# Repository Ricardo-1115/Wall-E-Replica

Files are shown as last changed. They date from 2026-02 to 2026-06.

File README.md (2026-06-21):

# WALL-E Robot — ESP32-S3 无线图传控制系统

<p align="center">
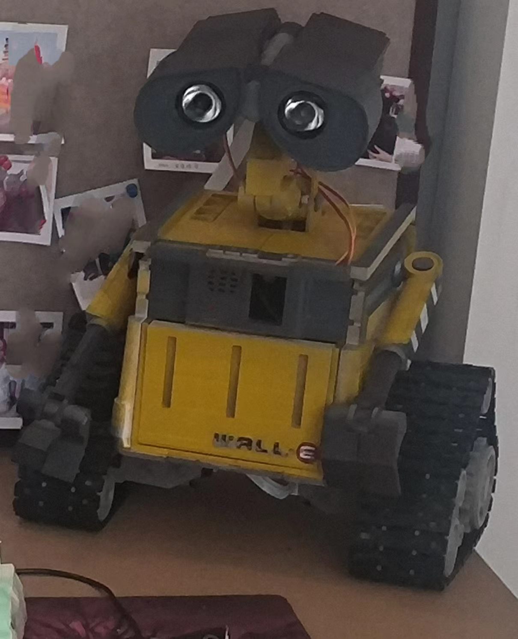
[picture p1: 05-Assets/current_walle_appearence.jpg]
WALL-E 整机外观
  
</p>

<p align="center">
  
  
  
  
</p>

> 深度复刻皮克斯 WALL-E 机器人，从 3D 打印到自研 PCB 再到 ESP-IDF 固件，全栈闭环。
>
> 本科毕业设计项目 —— 基于 ESP32-S3 的移动机器人无线图传系统设计与实现

---

## 目录

- [概述](#概述)
- [实物展示](#实物展示)
- [功能特性](#功能特性)
- [硬件架构](#硬件架构)
- [引脚映射](#引脚映射)
- [快速上手](#快速上手)
- [固件架构](#固件架构)
- [Web 控制面板](#web-控制面板)
- [通信协议](#通信协议)
- [性能测试](#性能测试)
- [硬件设计要点](#硬件设计要点)
- [项目结构](#项目结构)
- [致谢](#致谢)
- [许可证](#许可证)

---

## 概述

本项目全栈自研一台电影级别的 WALL-E 复刻机器人，集无线图传、远程控制、自主行为于一体。

**机械**：基于 [Chillibasket/walle-replica](https://github.com/chillibasket/walle-replica) 开源外壳，经 3D 打印、打磨、组装与喷漆涂装。

**硬件**：自研 12V 三路隔离电源分配板 + ESP32-S3 主控 PCB（窄铜桥接地解决电机地弹干扰）。

**固件**：基于 ESP-IDF 原生框架，FreeRTOS 多任务调度，组件化架构。

**通信**：WiFi STA 模式，WebSocket JSON 全双工协议（单向延迟 < 15ms），MJPEG 实时图传（24 FPS）。

---

## 实物展示

### 3D 打印表面处理

<p align="center">
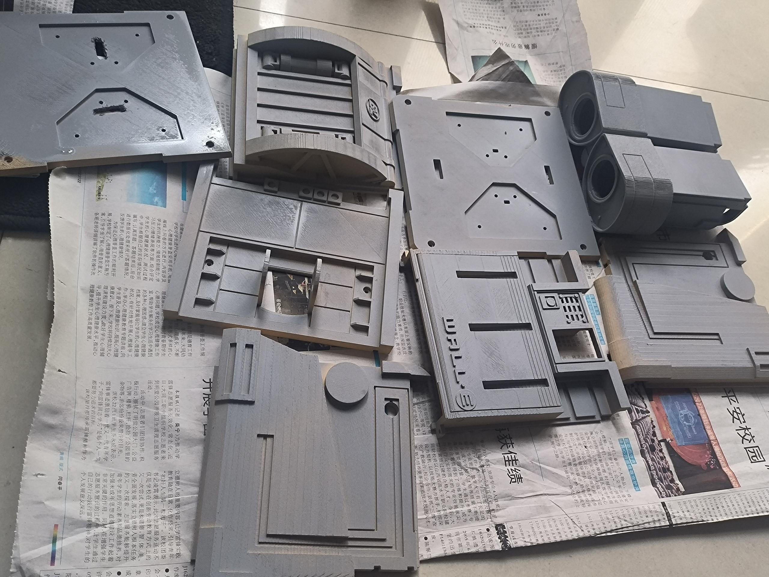
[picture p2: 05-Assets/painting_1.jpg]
喷漆过程
  
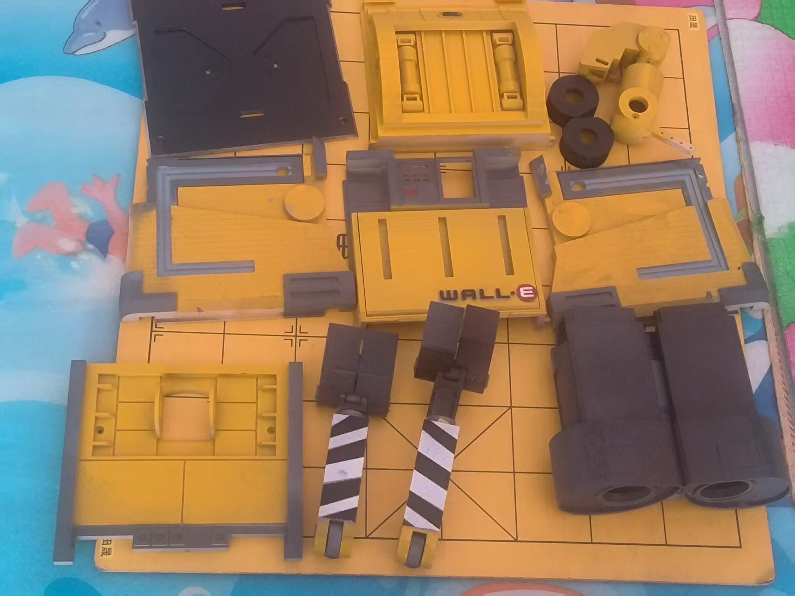
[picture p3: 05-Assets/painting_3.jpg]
喷漆完成
  
</p>

### 主控电路板布局布线

<p align="center">
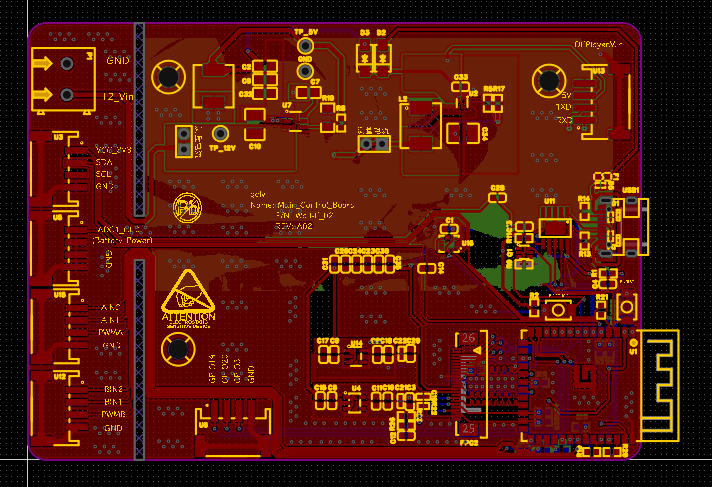
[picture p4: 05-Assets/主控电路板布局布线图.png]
PCB 布局
  
</p>

> 原理图：[02-Hardware/Main_Control_Board/SCH_WALL-E_MB_000_SCH_2026-06-01.pdf](./02-Hardware/Main_Control_Board/SCH_WALL-E_MB_000_SCH_2026-06-01.pdf)

---

## 功能特性

- **无线图传** — OV2640 摄像头 640×480 MJPEG 硬件编码，双缓冲推流，实测 24 FPS
- **全向运动** — 2 路直流电机（TB6612 驱动，LEDC 硬件渐变）+ 7 路舵机关节（PCA9685 驱动，平滑缓动插值）
- **Web 控制面板** — 零安装，手机/PC 浏览器即可操控，支持 Gamepad API 游戏手柄
- **音频交互** — DFPlayer Mini 播放电影原声音效（35+ 音效文件）
- **自主行为** — 8 套预设动画 + 7 种加权随机微表情 + 能量驱动行为决策
- **CLI 调试** — UART 串口控制台提供舵机/电机/音频/NVS 调试命令
- **电池管理** — ADC 电压监测 + 滑动平均滤波 + 低电量加速衰减
- **安全保护** — 电机 800ms 心跳超时自动刹车

---

## 硬件架构

```
                               ┌──────────────────┐
12V LiPo ──► 电源分配板 ──┬──► │ 驱动板 (电机/舵机)│
 (3S)      (3路隔离输出)    │    └──────────────────┘
                           │
                     ┌─────▼──────────────────────────┐
                     │      ESP32-S3 主控板             │
                     │  ┌──────────────────────────┐  │
                     │  │ ESP32-S3-WROOM-1 (N16R8) │  │
                     │  │ 16MB Flash / 8MB PSRAM   │  │
                     │  └──────┬───────┬───────────┘  │
                     │    I2C  │  DVP  │  UART         │
                     │  ┌──────┘       ▼              │
                     │  │    ┌──────────────────┐     │
                     │  │    │ OV2640 摄像头     │     │
                     │  │    │ 640×480 JPEG     │     │
                     │  │    └──────────────────┘     │
                     │  │                             │
                     │  ▼                             │
                     │  ┌──────────────────┐          │
                     │  │ PCA9685 舵机驱动 │──► 7舵机 │
                     │  ├──────────────────┤          │
                     │  │ SSD1306 OLED     │ 128×64   │
                     │  ├──────────────────┤          │
                     │  │ DFPlayer Mini    │──► 喇叭  │
                     │  └──────────────────┘          │
                     └────────────────────────────────┘
```

### 电源分配板
- 12V 输入（3S LiPo），3 路独立输出（PMOS 主开关）
- 保护：TVS + 防反接肖特基 + PTC 自恢复保险 + 两级电容滤波

### 主控板电源树
```
12V ──► TPS54308 (12V→5V, 3A) ──► TLV62569 (5V→3.3V, 2A)
                                      ├── ME6211 (3.3V→2.8V, OV2640 AVDD)
                                      └── ME6211 (3.3V→1.2V, OV2640 DVDD)
```

---

## 引脚映射

| 外设 | 接口 | 引脚 | 备注 |
|---|---|---|---|
| **左电机** | LEDC PWM | GPIO38 | 4kHz, 13-bit |
| | DIR1/2 | GPIO39, GPIO40 | |
| **右电机** | LEDC PWM | GPIO2 | 4kHz, 13-bit |
| | DIR1/2 | GPIO41, GPIO42 | |
| **I2C 总线** | SDA/SCL | GPIO4, GPIO5 | 400kHz, 2.2kΩ 上拉 |
| **PCA9685** | I2C addr | 0x40 | 7 路舵机 |
| **SSD1306 OLED** | I2C addr | 0x3C | 128×64 |
| **DFPlayer Mini** | UART2 TX/RX | GPIO6, GPIO7 | 9600 baud |
| **OV2640 摄像头** | DVP 8-bit | GPIO8~18 | 12 引脚并行 |
| | SCCB (I²C-like) | GPIO47, GPIO48 | 配置总线 |
| **电池 ADC** | ADC1_CH0 | GPIO1 | 2.5dB 衰减, 12-bit |
| **UART0 控制台** | TX/RX | GPIO43, GPIO44 | 通过 CH340K |

---

## 快速上手

### 前置依赖

- [ESP-IDF v5.5](https://docs.espressif.com/projects/esp-idf/en/v5.5/esp32s3/get-started/) 或更高版本
- USB 转 UART 驱动（CH340K）
- Python 3（ESP-IDF 安装时自带）

### 构建

```bash
cd 03-Software/Walle26
idf.py set-target esp32s3
idf.py build
```

### 烧录

```bash
idf.py -p /dev/ttyUSB0 flash   # Linux/macOS
idf.py -p COM3 flash            # Windows
```

### 配置 WiFi

编辑 `sdkconfig.defaults` 中的 WiFi SSID 和密码，或通过 menuconfig 配置：

```bash
idf.py menuconfig
# 路径: WiFi Configuration > WiFi SSID / WiFi Password
```

### 连接

1. 给机器人上电（12V 3S LiPo）
2. 等待 ESP32 连接 WiFi（串口日志查看 IP 地址，`ESP_LOGI("WIFI", "获取到 IP: ...")`）
3. 浏览器访问 `http://<ESP32-IP>` 打开控制面板
4. 视频流地址：`http://<ESP32-IP>:8081/stream`
5. 串口监视器：`idf.py -p <PORT> monitor`

---

## 固件架构

### 组件化分层

```
main.c (初始化 + 任务创建)
│
├── Servo/              PCA9685 I2C 驱动 + 20ms 缓动插值任务
├── DC_Motor/            LEDC 硬件异步渐变 + 800ms 心跳安全刹车
├── wifi/                WiFi STA + HTTP + WebSocket + MJPEG 推流
│   ├── camera_app.c     OV2640 初始化与双缓冲帧管理
│   ├── ws_handler        JSON 指令解析与分发
│   └── index.html        Web 控制面板（内嵌固件）
├── animation_engine/     8 套关键帧动画 + 7 种微表情生成器
├── energy_manager/       0~100 能量值驱动行为决策状态机
├── battery/              ADC 采样 + 8 阶滑窗滤波 + LiPo 查表
├── DFPlayerMini/         UART 串口音频播放
├── command/              CLI 调试命令（舵机/电机/音频/NVS/动画）
└── display/              SSD1306 电池电量显示
```

### 任务调度 (FreeRTOS)

| 核心 | 任务 | 优先级 | 周期 |
|---|---|---|---|
| Core 0 | `wifi_app_task` | — | 事件驱动 |
| Core 1 | `motor_ctrl_task` | 15 | 队列驱动 + 心跳 |
| Core 1 | `servo_fade_task` | — | 20ms |
| Core 1 | `servo_logic_task` | — | 队列驱动 |
| Core 1 | `anim_engine_task` | 8 | 队列驱动 |
| Core 1 | `energy_mgr_task` | 6 | 1s |
| Core 1 | `battery_task` | — | 1s |

### 控制流示例：WebSocket → 舵机

```
浏览器 ── WebSocket JSON ──► ws_handler
                                  │
                            energy_manager ← ENGAGED
                                  │
                            servo_cmd_queue (覆盖写)
                                  │
                            servo_control_task
                                  │
                            walle_joint_move()
                                  │
                            servo_fade_task (20ms 缓动插值)
                                  │
                            PCA9685_set_angle() ──► 舵机
```

### 能量管理行为决策

无人操控时，能量以 0.08/s 衰减（低电量翻倍），自动选择区间对应的动画：

```
 能量 80~100 ── 微表情（7 种加权随机）
 能量 40~80  ── 好奇/探索（预设动画）
 能量 10~40  ── 低落/害羞
 能量 0      ── 假寐姿态
```

WebSocket 有活动时立即切回 `ENGAGED`（能量 = 100），恢复远程控制。

---

## Web 控制面板

内置于固件的 HTML5 控制面板，无需安装任何 App，浏览器访问 `http://<ESP32-IP>` 即可使用。

### 功能

| 功能 | 说明 |
|---|---|
| **实时状态** | HTTP `/status` 轮询显示电量、能量、表情状态 |
| **关节可视化** | 7 路关节进度条实时显示，WebSocket 50ms 高频推送 |
| **链路状态** | 连接/断开/重连指示器 |
| **游戏手柄** | Browser Gamepad API，摇杆控履带，扳机控手臂 |
| **MJPEG 图传** | 640×480 实时视频，按钮启停 |
| **调试面板** | 实时显示收发 JSON 数据帧 |

### 控制台布局示意

```
┌──────────────────────────────────────────────┐
│  ⬡ WALL-E                              78% 😊 │
├──────────────────┬───────────────────────────┤
│  系统             │  关节                     │
│  IP: 192.168.x.x │  头部 ████████░░ 68       │
│  链路 ● ONLINE   │  脖顶 ██████░░░░ 52       │
│  手柄 ● READY    │  左眼 ██░░░░░░░░ 20       │
│                   │  右眼 ████████░░ 70       │
│  动力             │  左臂 ░░░░░░░░░░  0       │
│  左履带 ████ 45   │  右臂 ░░░░░░░░░░  0       │
│  右履带 ███ -30   │                           │
├──────────────────┴───────────────────────────┤
│  📷 启动图传                                   │
├──────────────────────────────────────────────┤
│  {"L":45,"R":-30,"S":[68,52,48,20,70,0,0]}   │
└──────────────────────────────────────────────┘
```

---

## 通信协议

### WebSocket (ws://`<ESP-IP>`/ws)

JSON 格式双向通信：

```json
{
  "L": 50,           // 左履带速度 (-100 ~ 100)
  "R": -30,          // 右履带速度 (-100 ~ 100)
  "S": [50,50,50,50,50,30,30],  // 7 关节角度 (0~100)
  "D": 100           // 舵机动作持续时间 (ms)
}
```

服务端回显收到的帧，用于客户端计算 RTT。

### MJPEG 流 (http://`<ESP-IP>`:8081/stream)

- 协议：`multipart/x-mixed-replace`
- 分辨率：640×480 (VGA)
- 编码：硬件 JPEG
- 帧率：~24 FPS
- 双缓冲：`fb_count = 2`

### REST API

| 端点 | 方法 | 返回 |
|---|---|---|
| `/status` | GET | JSON（电量、能量、WiFi 信号等） |
| `/` | GET | Web 控制面板 HTML |

---

## 性能测试

### WebSocket 延迟（端到端单向）

| 场景 | 单向延迟 |
|---|---|
| 同房间 3m 无遮挡 | **12.46 ms** |
| 隔一堵混凝土墙 5m | **13.22 ms** |
| 隔两堵墙 10m | **48.14 ms** |

所有场景 ≤ 50ms，满足设计指标。

### MJPEG 帧率

| 采样帧数 | 帧率 |
|---|---|
| 100 帧 | 23.6 FPS |
| 500 帧 | **24.2 FPS** |

超设计目标 15 FPS 约 57%。

### 电源纹波

| 转换器 | 开关频率 | 纹波 |
|---|---|---|
| TPS54308 (12V→5V) | 358 kHz | 6.38 mVp-p |
| TLV62569 (5V→3.3V) | 1.27 MHz | 9.70 mVp-p |

<p align="center">
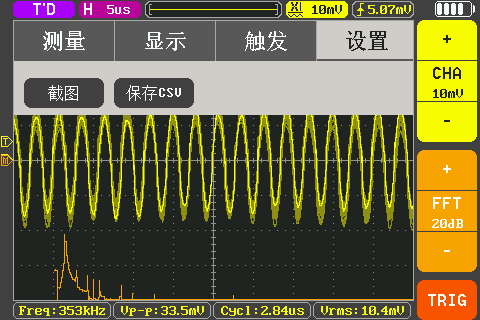
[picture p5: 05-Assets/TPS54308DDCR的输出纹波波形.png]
TPS54308 纹波
  
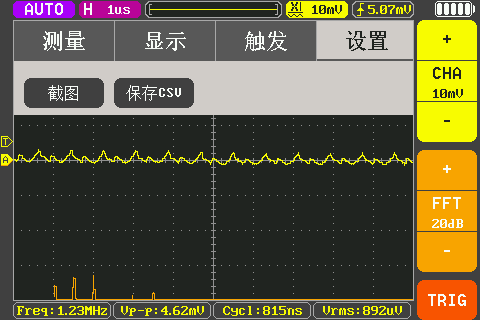
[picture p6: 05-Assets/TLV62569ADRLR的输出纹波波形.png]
TLV62569 纹波
  
</p>

### 舵机精度

控制误差 ±0.5°~1°（受舵机死区限制），优于设计指标 ±2°。

---

## 硬件设计要点

> 本项目的核心难点：电机/舵机感性负载的高频地弹噪声对主控芯片的传导干扰。

### 窄铜桥接地（Split-Ground-Plane Bridge）

PCB 分为洁净区（MCU 数字地）和污染区（电机电源地），中间以 **4~5mm 宽顶底双层覆铜桥** 作为两地唯一连接点：

- **信号回流**：所有跨区信号线紧贴铜桥上方走线，回流紧贴桥底返回，环路面积 ≈ 0
- **噪声扼制**：高频噪声冲击窄桥时，窄覆铜的寄生电感形成扼流效应，将噪声逼回电源粗线路径

辅助措施：PWM 线串联 100Ω 抑制过冲，I²C 2.2kΩ 上拉增强抗扰，XCLK/PCLK 串联 22Ω 保证图像完整性。

---

## 项目结构

```
WallE_Graduation/
├── 01-Spec/                 设计需求、引脚分配、命名规范
├── 02-Hardware/             原理图 (PDF)
│   ├── Power_Distribution_Board/
│   └── Main_Control_Board/
├── 03-Software/Walle26/     ESP-IDF 固件项目
│   ├── main/main.c          主入口
│   ├── Components/          组件化驱动
│   │   ├── Servo/           舵机 (PCA9685 + 平滑动画)
│   │   ├── DC_Motor/        直流电机 (LEDC 渐变)
│   │   ├── DFPlayerMini/    音频
│   │   ├── wifi/            WiFi + WebSocket + MJPEG + Web UI
│   │   ├── animation_engine/ 动画引擎
│   │   ├── energy_manager/  能量管理
│   │   ├── battery/         电池监测
│   │   ├── command/         CLI 调试命令
│   │   └── display/         OLED 显示
│   └── managed_components/  依赖组件
├── 04-Mechanical/           3D 打印 STL (~70 文件)
├── 05-Assets/               照片、视频、音效参考
└── 06-Thesis/               毕业论文 + 流程图 + 参考文献
```

---

## 致谢

### 机械原型
- [Chillibasket/walle-replica](https://github.com/chillibasket/walle-replica) — WALL-E 外壳开源设计

### 技术参考
- Espressif ESP-IDF 物联网开发框架
- TI SPRAAS1B — *Hardware Design Guidelines for TMS320F28xx*
- [Split Ground Planes — The Most Persuasive Argument Yet](https://hott.shielddigitaldesign.com/techtips/split-gnd-plane.html)

### 开源组件
- [nixy4/u8g2](https://components.espressif.com/components/nixy4/u8g2) — OLED 图形库
- [espressif/esp32-camera](https://github.com/espressif/esp32-camera) — 摄像头驱动
- [espressif/esp_jpeg](https://components.espressif.com/components/espressif/esp_jpeg) — JPEG 编解码

### 第三方改进模型
- WALL-E (Tracks strong linkages) — Thingiverse 4932310
- Pinion gear secured with grub screw — Thingiverse 4932959
- WALL-E modified wheel frame — Thingiverse 4832742
- Walle OLED frame — Thingiverse 4800908
- WALL-E paperclip replacement — Thingiverse 4707426
- Accurate Recording Buttons — Thingiverse 5223648

### 原创贡献

1. **平台迁移**：Arduino → ESP-IDF 原生 FreeRTOS 多任务架构
2. **窄铜桥接地**：自研电源分配板 + 混合信号 PCB 布局，解决电机地弹
3. **低延迟通信**：HTTP 轮询 → WebSocket 全双工 JSON，延迟降至 15ms
4. **全功能集成**：图传 + 运动 + 音频 + CLI + 动画 + 能量管理于单一 ESP32-S3
5. **能量行为系统**：单指标 (0~100) 驱动的自主行为决策
6. **零安装 Web 面板**：基于 WebSocket + Gamepad API 的实时操控界面

---

## 许可证

本项目基于 GPL v3 协议开源。

Copyright (C) 2026 gclv (Ricardo-1115)
Copyright (C) 2023 Chillibasket (Original Mechanical Design)

```
This program is free software: you can redistribute it and/or modify
it under the terms of the GNU General Public License as published by
the Free Software Foundation, either version 3 of the License.
```

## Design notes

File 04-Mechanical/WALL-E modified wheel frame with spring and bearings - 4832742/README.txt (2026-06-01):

WALL-E modified wheel frame with spring and bearings by dmdiego on Thingiverse: https://www.thingiverse.com/thing:4832742

Summary:
This is a remix ofhttps://www.thingiverse.com/thing:4285247 andhttps://www.thingiverse.com/thing:4795733So that both bearings and springs can be fitted to the wheel assembly of Wall-EIf needed, file or sandpaper the "functional part" to make it fit properly.My tracks are already using paper clip linkages.https://www.thingiverse.com/thing:4932310https://www.youtube.com/watch?v=lATBx3MUcMY (moves really smooth and quiet)

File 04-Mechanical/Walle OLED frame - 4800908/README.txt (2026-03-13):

Walle OLED frame by ZDC on Thingiverse: https://www.thingiverse.com/thing:4800908

Summary:
I made a frame for using a OLED to monitor a 12v lipo battery.This fits the existing hole, I used some superglue (CA glue) to glue the frame in place.Note the directions of the frame insertAfter I used just a small amount of hot glue to hold the OLED in place.This is OLED I used.https://www.banggood.com/Geekcreit-0_96-Inch-4Pin-White-IIC-I2C-OLED-Display-Module-12864-LED-Geekcreit-for-Arduino-products-that-work-with-official-Arduino-boards-p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

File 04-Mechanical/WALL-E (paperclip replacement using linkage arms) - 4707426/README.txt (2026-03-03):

WALL-E (paperclip replacement using linkage arms) by ZDC on Thingiverse: https://www.thingiverse.com/thing:4707426

Summary:
Remixed from:https://www.thingiverse.com/thing:3703555&amp;https://www.thingiverse.com/thing:4583962Frustrated with trying to figure out how to get the eyes to work with paperclips or the remixed head center I decided why not make simple linkages to connect the eye servos arms to the eye head center piece. I also included the hole as per rene1960's center head design so you can attached the head to his neck piece remixes so you don't have to glue the head to the neck as the original design.The parts I posted are the only ones needed to make this work.In the process I found out my servos needed to be reverse looking at rene1960 photos of the center head remix they did. The original design reference photos from chillibasket showed them the way which is how I originally had them which after trying to wrap my head around how the eyes are suppose work with the servo seemed not correct which seemed odd for how well documented they had everything, but maybe it was just me.I also redesigned the center head piece to make the linkages work.I used M2 machine screws for the connections for the linkages on the 2nd last hole on the servo arms. I drilled the servo hole slightly larger to make the screws fit.Note: The linkages holes are meant so they move freely around the screw attached to the center head piece and servo arm. Also not the direction I attached the machine screws for the linkages, it was hard to get good photos to show how I did it.This is not no other modifications are required to other parts.I also added to extra holes for custom adjustments if needed.If anyone wants STEP versions just comment or send me a message and I can post them.

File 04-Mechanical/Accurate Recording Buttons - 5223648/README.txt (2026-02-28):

Accurate Recording Buttons by Xyphinon on Thingiverse: https://www.thingiverse.com/thing:5223648

Summary:
The original buttons were just circles but the real Wall-e has different shaped buttons, so I made this.

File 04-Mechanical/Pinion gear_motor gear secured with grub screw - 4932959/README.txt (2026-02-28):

Pinion gear/motor gear secured with grub screw by dmdiego on Thingiverse: https://www.thingiverse.com/thing:4932959

Summary:
Remixed the pinion/motor gear to use M4x4mm grub screw to secure it firmly on the motor shaft.

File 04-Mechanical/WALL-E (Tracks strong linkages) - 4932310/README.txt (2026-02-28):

WALL-E (Tracks strong linkages) by ZDC on Thingiverse: https://www.thingiverse.com/thing:4932310

Summary:
I modified the tracks to be strong and use paperclip to connect them.The paperclip idea was from Eisbaeeer tracks that I originally used but they kept breaking on me were the paperclips went though there is not much plastic around them.https://www.thingiverse.com/thing:4069116I also redesigned the front as a gear to help keep the tracking alignment.These track are easy to print and require No support.Connecting the last track/tread &amp; Removing the paperclips can be difficult if you need to remove the tracks/tread.

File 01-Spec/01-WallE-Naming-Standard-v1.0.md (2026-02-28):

# 《WALL-E 机器人及平台编码管理规范》

## 1.目的

定义 "瓦力(WALL-E)" 机器人项目及其衍生平台(ESP32-S3等)的型号命名和序列号规则，确保研发，建模，程序迭代与实物组装的可追溯性。
## 2.适用范围

适用于本项目相关的3D模型版本，固件代码版本，PCB电路板版本及实物组装件。
## 3.产品型号命名规则

### 3.1 项目代号: WALL-E

### 3.2 字段说明

- 型号数字: 三位数组合(示例: 001)

  | 位数 | 代表含义 | 数字含义(0/1/2) |
  |:----:|:--------:|----------------|
  | 第1位 | 核心功能 | 0:图传+运动; 1：带AI功能 |
  | 第2位 | 硬件版本 | 0代表初代，数字随代次逐次增加； |
  | 第3位 | &#x274c; | &#x23f3; |

## 4.软件与文档版本控制

在毕设中，软件迭代最快，需增加版本控制:

- 格式:ProjectName_v [大版本] . [小版本] . [修正版]
- 示例:WallE_Firmware_v1 . 0 . 2
  
---

> **学习**是一个持续的过程，每一小步都是进步。

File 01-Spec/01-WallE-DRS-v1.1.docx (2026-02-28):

设计需求规格说明书

## 1 项目概述

## 1.1项目背景

本项目旨在复刻经典机器人形象 Wall-E，基于开源项目 Chillibasket 的机械结构进行改进。系统采用 ESP32-S3 作为单一主控单元，实现视觉图传、运动控制与人机交互的高度集成化设计。

## 1.2项目目标

实现Wall-E 外观与基本动作复刻和实时视频图传与远程控制。

## 2 系统总体架构设计

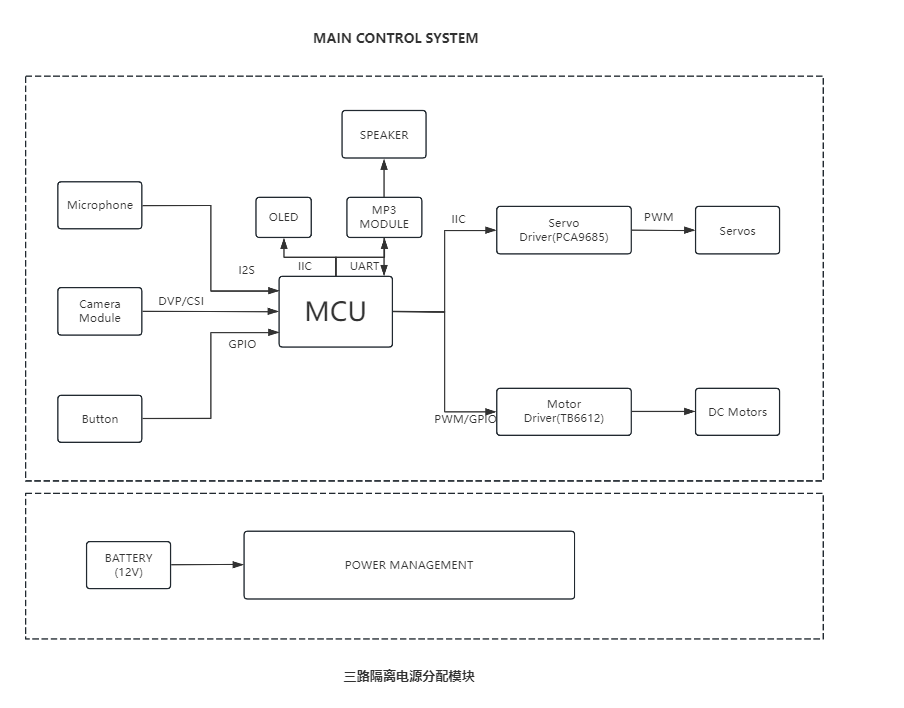
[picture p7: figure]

图2-1 系统硬件架构图

图 2-1 系统硬件架构图系统以 ESP32-S3 为核心控制单元，采用模块化设计。感知层通过 DVP 接口 采集 OV2640 视频流并显示在前端；执行层采用 I2C 总线 通信，通过 PCA9685 扩展芯片实现多路舵机的精准控制，同时利用 TB6612 驱动双路直流电机实现底盘运动。人机交互方面，集成了 1.3寸 OLED 用于状态显示，并通过 UART 串口 控制 MP3 模块实现语音反馈。

由于所用到的电机属于感性负载，在使用过程中容易产生反向电动势，如果将所有电机，主控及传感器的电源供应设计在一起，无疑增加了很大的难度，故Wall-E系统采用一个电源分开供电的策略，自行设计一块 三路隔离电源分配模块(12V-3 Channel Protected Power Distribution )电路板将12V锂电池组的电源分配给伺服电机，直流减速电机，主控板三路（具体如图2-2 电源架构图）

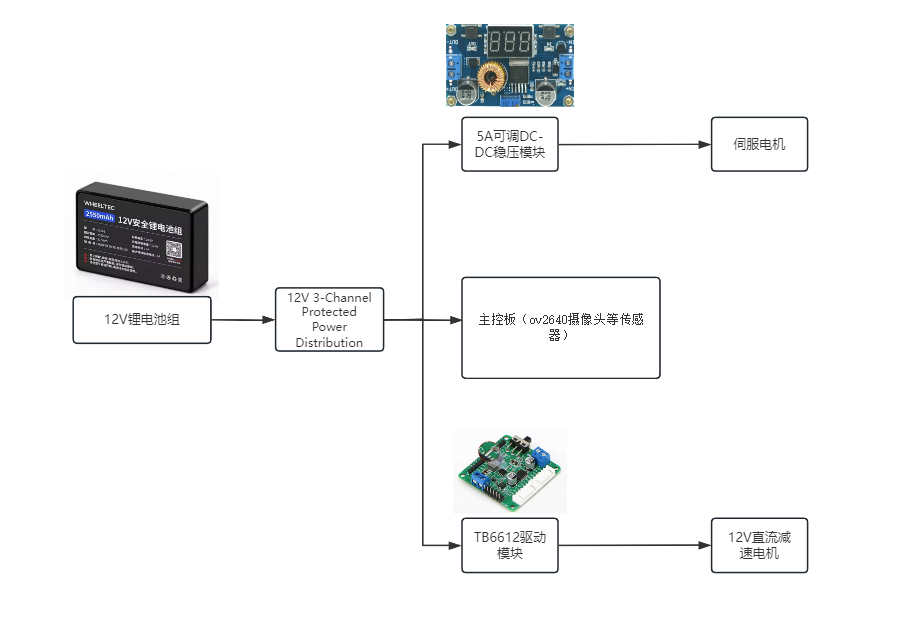
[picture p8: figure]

图2-2 电源架构图

## 3 性能规格

图传：在局域网环境下，实现分辨率不低于 320x240、帧率不低于 15FPS 的视频传输

控制：控制延迟小于 200ms

## 4 硬件接口详细定义

OV2640摄像头：

信号名称 | 分配GPIO | 备注
XCLK | GPIO10 | 外部时钟输入
PCLK | GPIO12 | 像素时钟
VSYNC | GPIO39 | 垂直同步（原JTAG MTCK，需禁用JTAG）
HREF | GPIO40 | 水平参考（原JTAG MTDO，需禁用JTAG）
D0-D7 | GPIO4,5,6,7,15,16,17,18 | 8位并行数据线
SIOD(SDA) | GPIO3 | 摄像头专用I2C数据（Strapping引脚，需外部上拉）
SIOC(SCL) | GPIO41 | 摄像头专用I2C时钟（原JTAG MTDI，需禁用JTAG）

音频系统：

信号名称 | 分配GPIO | 备注
I2S麦克风 SCK | GPIO38 | 麦克风时钟
I2S麦克风 WS | GPIO9 | 麦克风字选择
I2S麦克风 SD | GPIO8 | 麦克风数据
MP3模块 TX | GPIO11 | 串口发送
MP3模块 RX | GPIO21 | 串口接收

显示与舵机：

信号名称 | 分配GPIO | 备注
OLED SDA | GPIO13 | I2C数据（与PCA9685共用总线）
OLED SCL | GPIO14 | I2C时钟（与PCA9685共用总线）

电机驱动：

信号名称 | 分配GPIO | 备注
PWMA | GPIO42 | TB6612 PWM A（原JTAG MTMS，需禁用JTAG）
PWMB | GPIO2 | TB6612 PWM B
AIN1/AIN2 | PCA9685通道 | 通过PCA9685输出，不占用ESP32 GPIO
BIN1/BIN2 | PCA9685通道 | 通过PCA9685输出，不占用ESP32 GPIO

电量检测与调试接口：

信号名称 | 分配GPIO | 备注
Battery Sense | GPIO1 | ADC1_CH0，用于电压采样（ADC2与Wi-Fi冲突，故使用ADC1）
BOOT按钮 | GPIO9 | 按下接地（Strapping引脚，默认上拉，用于下载模式）
USB D- | GPIO8 | 内置USB串口/JTAG的D-，需串联22Ω电阻
USB D+ | GPIO11 | 内置USB串口/JTAG的D+，需串联22Ω电阻
UART0 TXD | GPIO21 | 备用调试输出（默认UART0引脚）
UART0 RXD | | 备用调试输入（默认UART0引脚）

## 5 软件功能与协议定义

视频传输： 采用 HTTP Server Push (MJPEG) 技术，通过独立的 Web Server 线程在 81 端口提供实时视频流，确保在 320x240 分辨率下达到 25FPS 的流畅度。

指令交互： 采用 WebSocket 协议 建立全双工通信通道。

下行指令： 包含电机 PWM 值、舵机角度、MP3 播放控制等，数据格式为 JSON。

上行遥测： 实时回传电池电压（经 ADC 采集）、Wi-Fi 信号强度 (RSSI) 及系统运行时间。

操控扩展性： 前端集成 HTML5 Gamepad API，支持通过标准 Xbox/PS 手柄直接映射控制机器人的运动与云台，实现沉浸式遥控体验。

## 6 机械结构适配说明

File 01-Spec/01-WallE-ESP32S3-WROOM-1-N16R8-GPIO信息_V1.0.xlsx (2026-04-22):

GPIO | 功能 | 注释 | 适用于ESP32-S3-WROOM-1-N16R8
GPIO0 | GPIO0, RTC_GPIO0 | Strapping管脚
GPIO1 | RTC_GPIO1, GPIO1, TOUCH1, ADC1_CH0
GPIO2 | RTC_GPIO2, GPIO2, TOUCH2, ADC1_CH1
GPIO3 | RTC_GPIO3, GPIO3, TOUCH3, ADC1_CH2 | Strapping管脚
GPIO4 | RTC_GPIO4, GPIO4, TOUCH4, ADC1_CH3
GPIO5 | RTC_GPIO5, GPIO5, TOUCH5, ADC1_CH4
GPIO6 | RTC_GPIO6, GPIO6, TOUCH6, ADC1_CH5
GPIO7 | RTC_GPIO7, GPIO7, TOUCH7, ADC1_CH6
GPIO8 | RTC_GPIO8, GPIO8, TOUCH8, ADC1_CH7, SUBSPICS1
GPIO9 | RTC_GPIO9, GPIO9, TOUCH9, ADC1_CH8, FSPIHD, SUBSPIHD
GPIO10 | RTC_GPIO10, GPIO10, TOUCH10, ADC1_CH9, FSPICS0, FSPIIO4, SUBSPICS0
GPIO11 | RTC_GPIO11, GPIO11, TOUCH11, ADC2_CH0, FSPID, FSPIIO5, SUBSPID
GPIO12 | RTC_GPIO12, GPIO12, TOUCH12, ADC2_CH1, FSPICLK, FSPIIO6, SUBSPICLK
GPIO13 | RTC_GPIO13, GPIO13, TOUCH13, ADC2_CH2, FSPIQ, FSPIIO7, SUBSPIQ
GPIO14 | RTC_GPIO14, GPIO14, TOUCH14, ADC2_CH3, FSPIWP, FSPIDQS, SUBSPIWP
GPIO15 | RTC_GPIO15, GPIO15, U0RTS, ADC2_CH4, XTAL_32K_P
GPIO16 | RTC_GPIO16, GPIO16, U0CTS, ADC2_CH5, XTAL_32K_N
GPIO17 | RTC_GPIO17, GPIO17, U1TXD, ADC2_CH6
GPIO18 | RTC_GPIO18, GPIO18, U1RXD, ADC2_CH7, CLK_OUT3
GPIO19 | RTC_GPIO19, GPIO19, U1RTS, ADC2_CH8, CLK_OUT2, USB_D-
GPIO20 | RTC_GPIO20, GPIO20, U1CTS, ADC2_CH9, CLK_OUT1, USB_D+
GPIO21 | RTC_GPIO21, GPIO21
GPIO22 | 不存在
GPIO23
GPIO24
GPIO25
GPIO26 | 该型号模组内部已用于Flash和PSRAM,不可用于其他功能
GPIO27
GPIO28
GPIO29
GPIO30
GPIO31
GPIO32
GPIO33
GPIO34
GPIO35
GPIO36
GPIO37
GPIO38 | GPIO38, FSPIWP, SUBSPIWP
GPIO39 | MTCK, GPIO39, CLK_OUT3, SUBSPICS1
GPIO40 | MTDO, GPIO40, CLK_OUT2
GPIO41 | MTDI, GPIO41, CLK_OUT1
GPIO42 | MTMS, GPIO42
GPIO43 | U0TXD, GPIO43, CLK_OUT1
GPIO44 | U0RXD, GPIO44, CLK_OUT2
GPIO45 | GPIO45 | Strapping管脚
GPIO46 | GPIO46 | Strapping管脚
GPIO47 | SPICLK_P_DIFF, GPIO47, SUBSPICLK_P_DIFF
GPIO48 | SPICLK_N_DIFF, GPIO48, SUBSPICLK_N_DIFF
加粗字体为默认功能

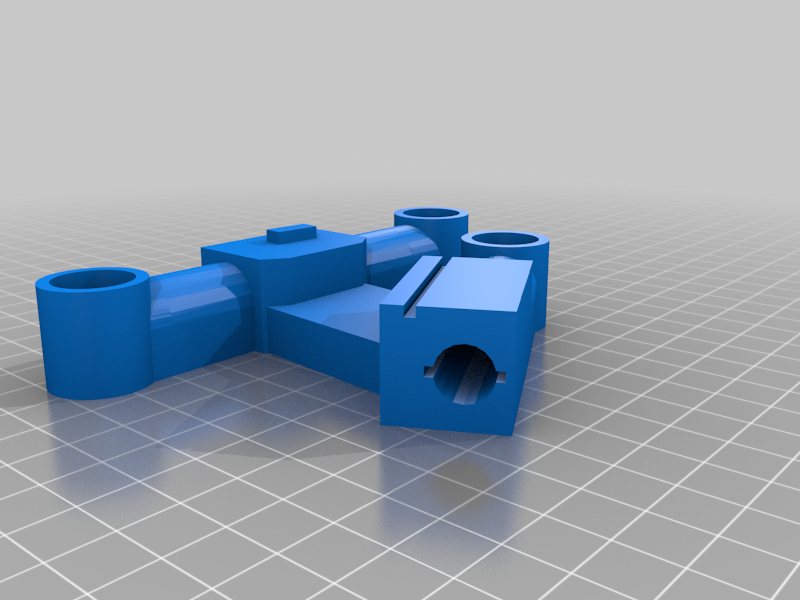
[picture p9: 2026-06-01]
04-Mechanical/WALL-E modified wheel frame with spring and bearings - 4832742/images/Left_Wheel_Frame_Bearings_and_spring.png

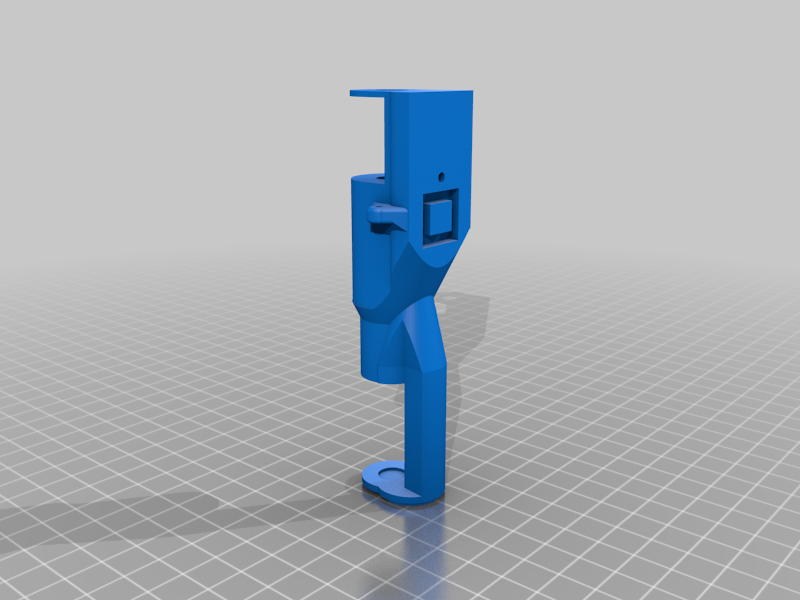
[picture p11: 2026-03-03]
04-Mechanical/WALL-E (paperclip replacement using linkage arms) - 4707426/images/Head_Center_MKIII.png

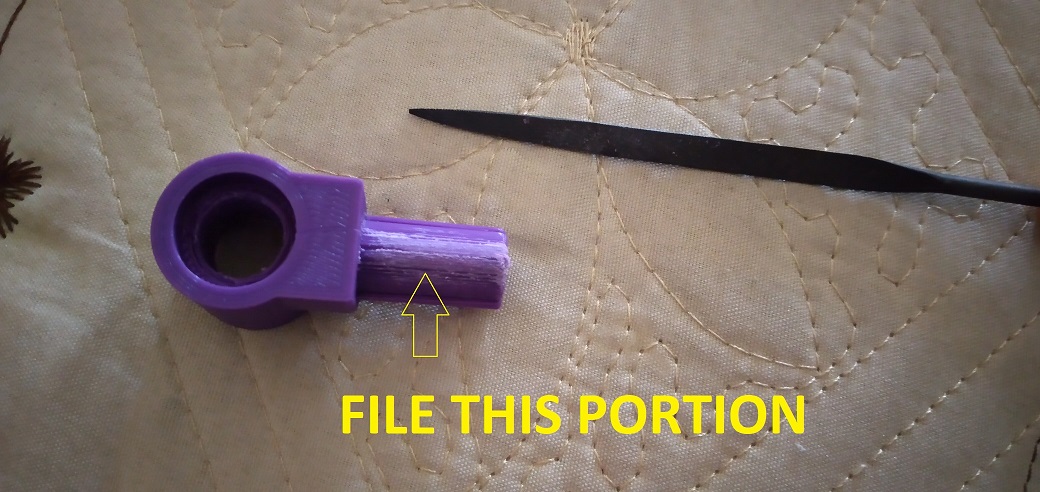
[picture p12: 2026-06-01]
04-Mechanical/WALL-E modified wheel frame with spring and bearings - 4832742/images/20210423_064734_mfnr.jpg

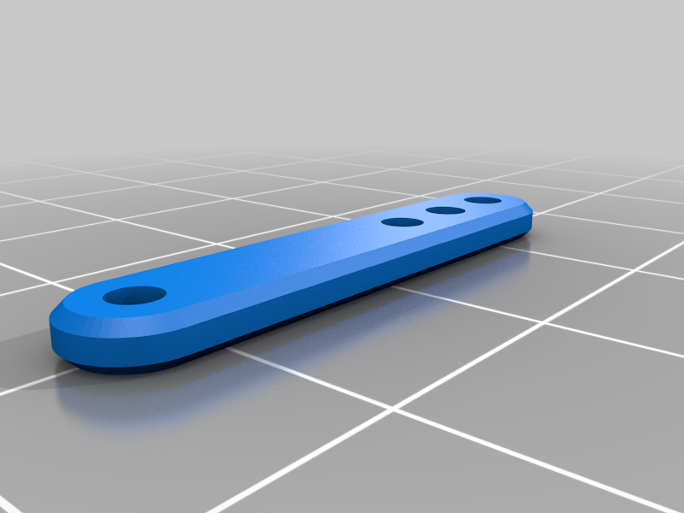
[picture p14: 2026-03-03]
04-Mechanical/WALL-E (paperclip replacement using linkage arms) - 4707426/images/Linkage_MKIII.png

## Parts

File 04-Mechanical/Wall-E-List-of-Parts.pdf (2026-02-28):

3D Printed WALL-E | List of Parts
# | Name | Quantity

3D Printed Components
Body
1 body-bottom | 1
2 body-back | 1
3 body-front | 1
4 body-front-door | 1
5 body-front-pins-x2 | 2
6 body-left | 1
7 body-right | 1
8 body-top | 1
9 body-neck-servo-holder | 1

Arms
10 arm-servo-bracket-left | 1
11 arm-servo-bracket-right | 1
12 arm-hinge-inner-x2 | 2
13 arm-hinge-outer-x2 | 2
14 arm-hinge-axle-x2 | 2
15 arm-barrel-x2 | 2
16 arm-barrel-end-x2 | 2
17 arm-piston-x2 | 2
18 hand-bracket-x2 | 2
19 hand-axle-x2 | 2
20 hand-finger-left-x2 | 2
21 hand-finger-right-x2 | 2
22 hand-finger-middle-x2 | 2

Head
23 head-center | 1
24 head-axle | 1
25 eye-back-left | 1
26 eye-back-right | 1
27 eye-middle-left | 1
28 eye-middle-right | 1
29 eye-front-left | 1
30 eye-front-right | 1
31 eye-camera-replica | 2
32 eye-camera-mount | 0 | <- Use this instead of eye-camera-replica
if you want to add a real camera Neck
33 neck-bottom-axle | 1
34 neck-bottom-left | 1
35 neck-bottom-linkage | 1
36 neck-bottom-right | 1
37 neck-middle-axle | 1
38 neck-top | 1
39 neck-round-bottom | 1

40 neck-round-top-left | 1
41 neck-round-top-right | 1
42 neck-wire-guide-left | 1
43 neck-wire-guide-right | 1
44 neck-top-linkage | 1

Wheels
45 wheel-back-x4 | 4
46 wheel-front-x4 | 4
47 wheel-top-x8 | 8
48 wheel-gear-driven-x2 | 2
49 wheel-gear-motor-x2 | 2
50 wheel-axle-notched-x6 | 6
51 wheel-axle-back-x2 | 2
52 wheel-axle-spacer-x8 | 8
53 wheel-frame-left | 1
54 wheel-frame-right | 1
55 wheel-frame-addon-x2 | 2
56 wheel-bracket-inner-left | 1
57 wheel-bracket-inner-right | 1
58 wheel-bracket-outer-left | 1
59 wheel-bracket-outer-right | 1

Tanks Treads
60 tread-plate-x70 | 70
61 tread-pin-x140 | 140
Total | 310

Hardware
h1 linkage bar (paper clip) | 2
h2 M3 Bolt - 10mm length | 14
h3 M3 Bolt - 20mm length | 12
h4 M3 Nut | 26

Electronics
e1 Micro Servo Motor | 7
e2 12v Geared DC Motor | 2
e3 Arduino Uno (or equivalent) | 1
e4 Motor Controller Shield | 1
e5 i2c Servo Controller | 1
e6 12v Battery Pack | 1
e7 12V to 5V Buck Converter | 1
e8 Raspberry Pi | 1 | Optional
e9 5v Battery Pack | 1
e10 USB Camera | 1
e11 Small Speaker | 1

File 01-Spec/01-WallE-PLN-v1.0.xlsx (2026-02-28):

阶段 | 编号 | 任务名称 | 核心产出物 | 开始日期 | 预计结束日期 | 状态 | 关键点
Z1:筹备 | 1.1 | 需求功能梳理 | 设计规格书（DRS） | 2026-01-16 | 2026-02-04 | 完成
Z2:结构 | 2.1 | Fusion软件学习，熟悉3D建模设计 | Wall-E初步3D结构 | 2026-01-20 | 2026-02-14 | 进行中
 | 2.2 | 3D打印机相关学习使用 | Wall-E最终3D结构 | 2026-02-15 | 2026-03-15 | 待开始
Z3:硬件 | 3.1 | 硬件电路设计 | PCBA,BOM | 2026-02-20 | 2026-04-01 | 待开始
Z4:软件 | 4.1 | 熟悉开发环境（ESP-IDF）及相关组件驱动 | 软件设计文档 | 2026-01-20 | 2026-02-14 | 待开始 | 验证摄像头驱动
 | 4.2 | 软件通讯协议 |  | 2026-01-20 |  | 待开始
 | 4.3 | 软件源代码 |  | 2026-03-03 |  | 待开始
Z5:交付 | 5.1 | 最终联调，文档整理撰写，产品宣发 | 毕业设计论文 |  |  | 待开始

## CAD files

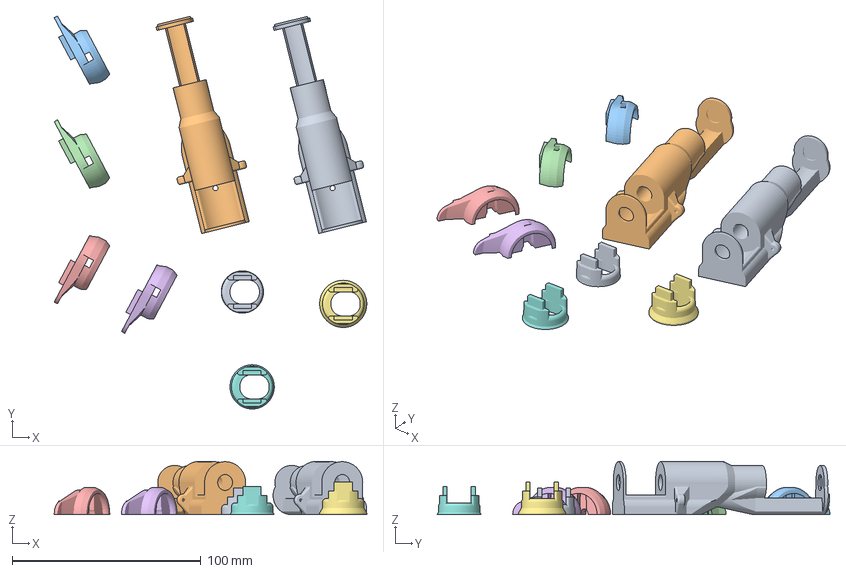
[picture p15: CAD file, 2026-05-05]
04-Mechanical/001_Original_Files/arm-barrel-end-x2.3mf
165.4 x 208.0 x 28.2 mm
Head_Center_MKIII.stl x 2
neck-round-top-left.STL x 2
neck-round-top-right.STL x 2
neck-round-bottom.STL
neck-round-bottom.STL_B x 2

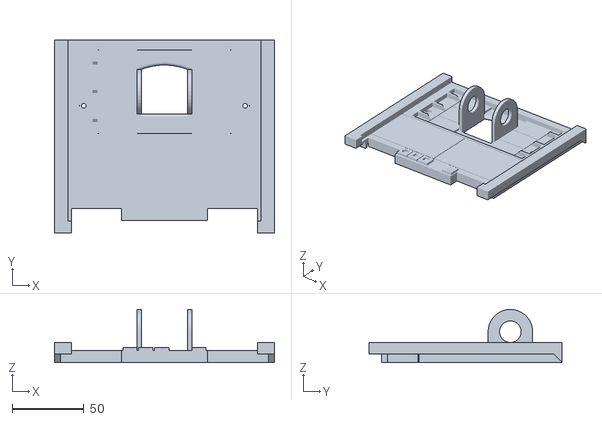
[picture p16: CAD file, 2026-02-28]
04-Mechanical/Accurate Recording Buttons - 5223648/files/New_Wall-e_Top.stl
153.0 x 134.4 x 37.0

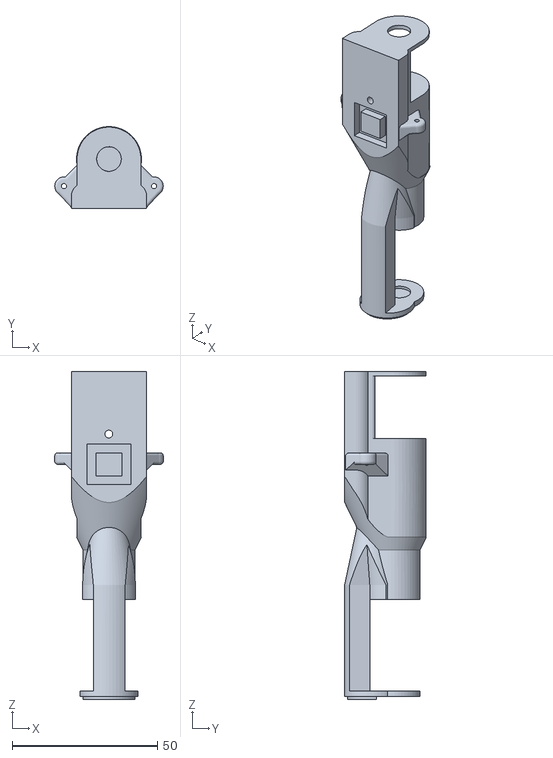
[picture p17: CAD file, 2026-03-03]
04-Mechanical/WALL-E (paperclip replacement using linkage arms) - 4707426/files/Head_Center_MKIII.stl
37.4 x 28.2 x 113.0

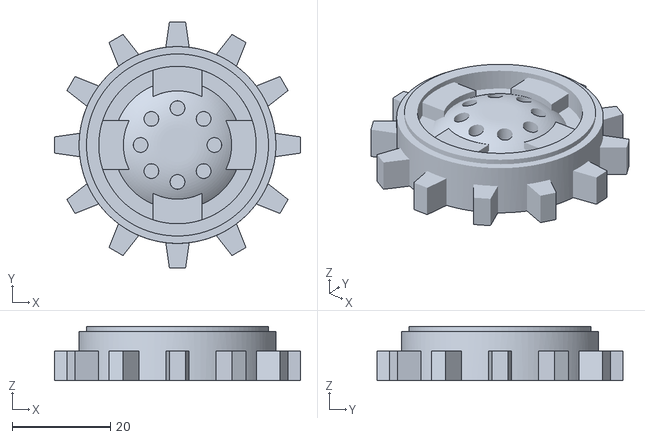
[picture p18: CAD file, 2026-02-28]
04-Mechanical/WALL-E (Tracks strong linkages) - 4932310/files/wheel-frontx4_MKII.stl
50.0 x 50.0 x 11.0

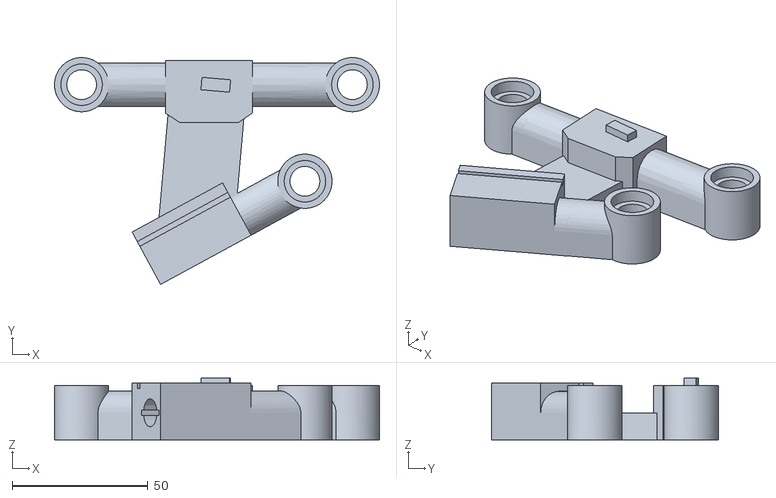
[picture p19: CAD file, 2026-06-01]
04-Mechanical/WALL-E modified wheel frame with spring and bearings - 4832742/files/Left_Wheel_Frame_Bearings_and_spring.stl
119.9 x 83.7 x 22.8

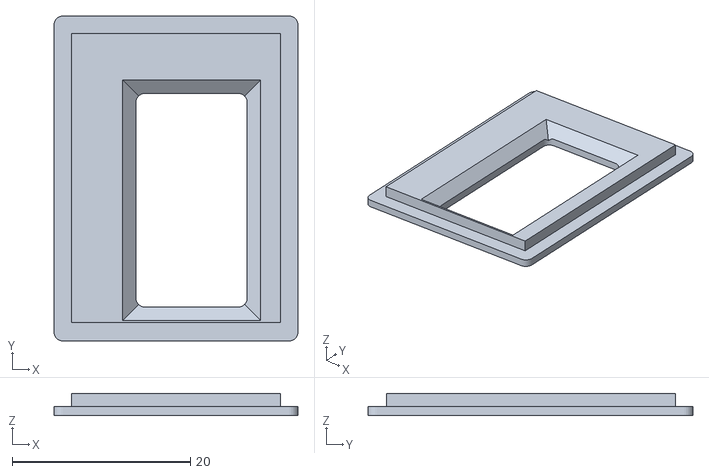
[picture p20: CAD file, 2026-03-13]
04-Mechanical/Walle OLED frame - 4800908/files/OLED_frame_v2.stl
27.4 x 36.5 x 2.50

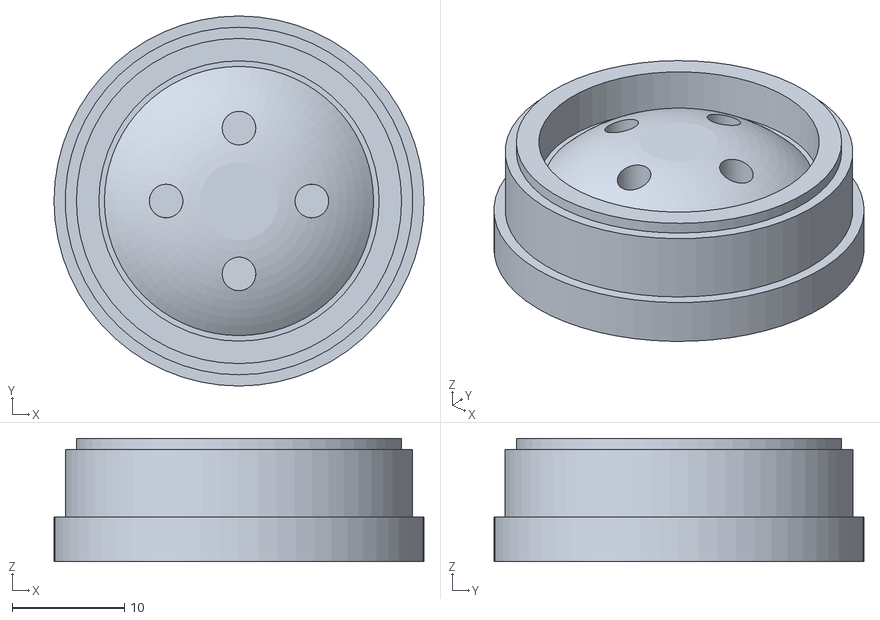
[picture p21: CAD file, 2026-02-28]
04-Mechanical/001_Original_Files/wheel-top-larger-x0.STL
33.0 x 33.0 x 11.0

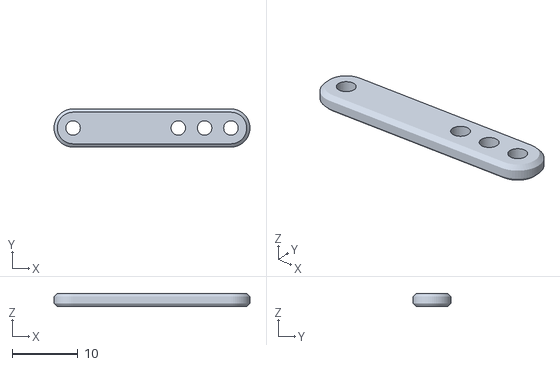
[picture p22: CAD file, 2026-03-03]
04-Mechanical/WALL-E (paperclip replacement using linkage arms) - 4707426/files/Linkage_MKIII.stl
29.8 x 5.80 x 2.00

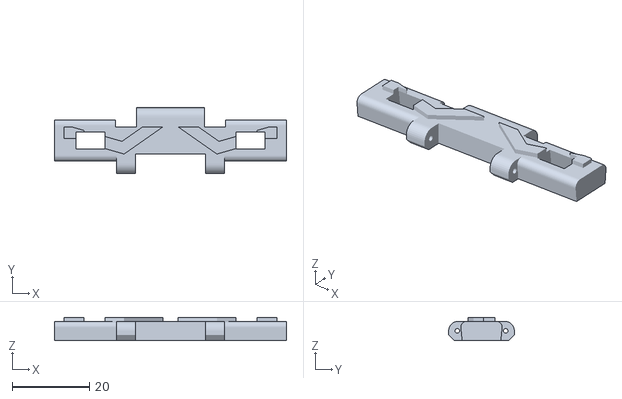
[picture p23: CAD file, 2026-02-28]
04-Mechanical/WALL-E (Tracks strong linkages) - 4932310/files/Tread_MKII.stl
60.0 x 17.0 x 6.00

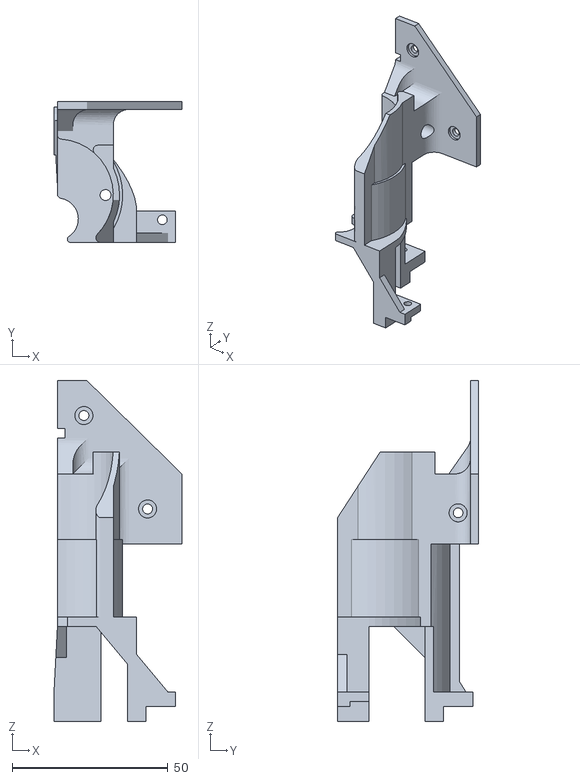
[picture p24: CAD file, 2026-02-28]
04-Mechanical/001_Original_Files/wheel-bracket-outer-left.STL
41.0 x 45.2 x 109.5

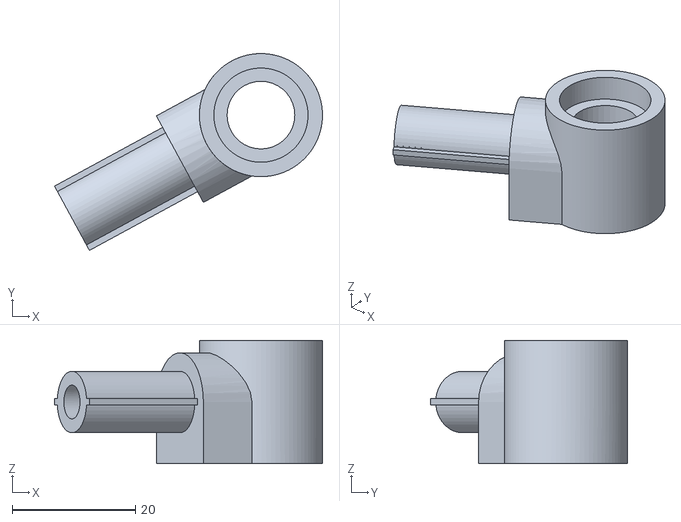
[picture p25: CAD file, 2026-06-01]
04-Mechanical/WALL-E modified wheel frame with spring and bearings - 4832742/files/functional_part_x_2.stl
43.5 x 32.0 x 20.0

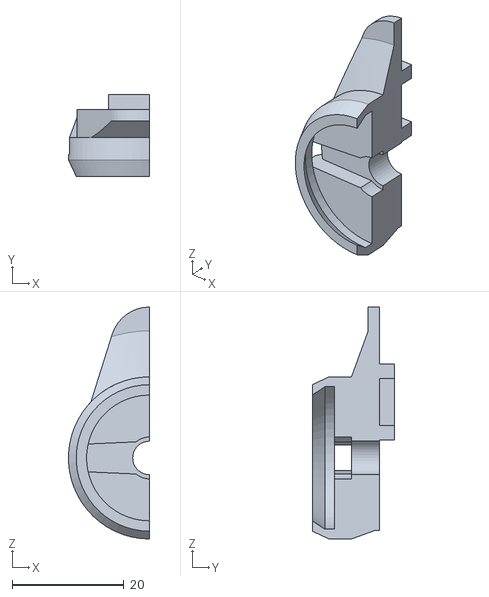
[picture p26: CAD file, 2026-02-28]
04-Mechanical/001_Original_Files/neck-round-top-left.STL
14.5 x 14.7 x 41.5

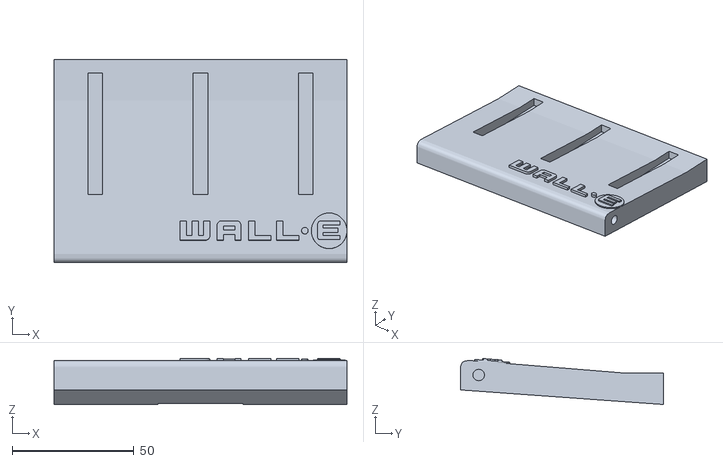
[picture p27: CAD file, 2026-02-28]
04-Mechanical/001_Original_Files/body-front-door.STL
120.5 x 83.5 x 18.9

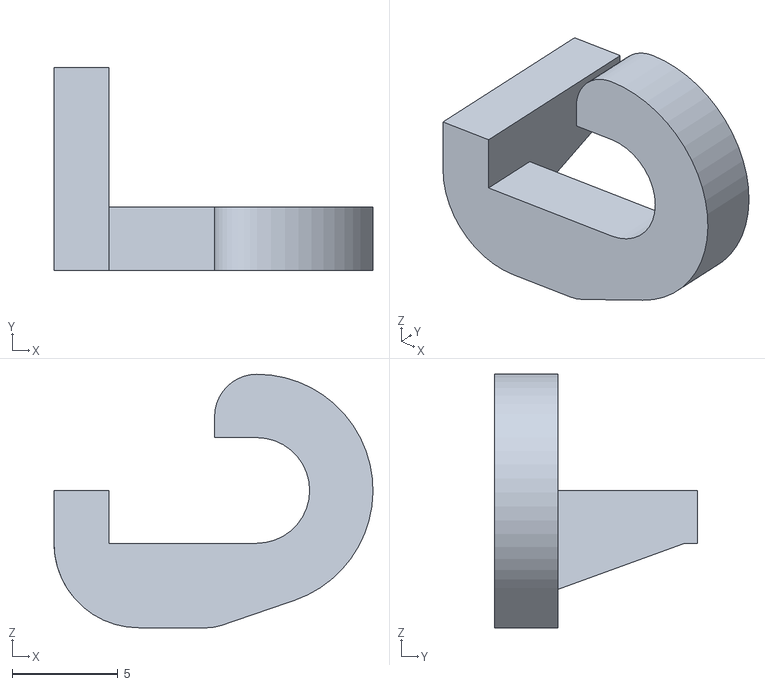
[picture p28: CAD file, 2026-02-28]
04-Mechanical/001_Original_Files/neck-wire-guide-right.STL
15.1 x 9.60 x 12.0

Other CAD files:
04-Mechanical/WALL-E modified wheel frame with spring and bearings - 4832742/files/Right_Wheel_Frame_Bearings_and_spring..stl
04-Mechanical/001_Original_Files/eye-back-left.STL
04-Mechanical/001_Original_Files/body-neck-servo-holder.STL
04-Mechanical/001_Original_Files/wheel-frame-right.STL
04-Mechanical/001_Original_Files/arm-barrel-end-x2.STL
04-Mechanical/001_Original_Files/arm-barrel-x2.3mf
04-Mechanical/001_Original_Files/arm-barrel-x2.STL
04-Mechanical/001_Original_Files/arm-hinge-axle-x2.STL
04-Mechanical/001_Original_Files/arm-hinge-inner-x2.STL
04-Mechanical/001_Original_Files/arm-hinge-outer-x2.STL
04-Mechanical/001_Original_Files/arm-piston-x2.STL
04-Mechanical/001_Original_Files/arm-servo-bracket-left.STL
04-Mechanical/001_Original_Files/arm-servo-bracket-right.STL
04-Mechanical/001_Original_Files/body-back.STL
04-Mechanical/001_Original_Files/body-bottom.STL
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

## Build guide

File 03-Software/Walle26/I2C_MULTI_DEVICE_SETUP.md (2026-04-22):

# I2C 一主多从集成方案

## 概述

本方案实现了 ESP32 中 **I2C 一主多从** 的集中管理，在**同一条 I2C 总线**（I2C_NUM_0）上连接多个从设备：

- **PCA9685**（PWM/舵机控制器）- 地址 `0x40`
- **SSD1306 OLED**（显示屏）- 地址 `0x3C`

### 硬件连接

- **I2C 引脚**：SDA = GPIO38，SCL = GPIO14
- **时钟速率**：400 kHz
- **通信协议**：I2C Master with multiple I2C Slave devices

---

## 系统架构

### 之前的问题

```
❌ PCA9685.c        创建自己的 I2C 总线（重复初始化）
❌ main.c (U8G2)    创建另一条 I2C 总线
→ 结果：两条独立的 I2C 总线，浪费资源，可能冲突
```

### 改进后的架构

```
✅ main.c
   └─ init_i2c_bus()           ← 创建唯一的 I2C 总线
      |
      ├─ init_servo_hardware()  ← 使用共享总线
      |  └─ servo_hw_init(bus_handle)
      |
      └─ init_oled_display()   ← 使用共享总线
         └─ u8g2_esp32_i2c_init_with_bus(ctx, bus_handle)
```

---

## 修改详情

### 1. **PCA9685.c** - 添加支持外部 bus_handle

**新增函数：**

```c
esp_err_t pca9685_init_with_bus(i2c_master_bus_handle_t bus_handle)
```

**原有函数保留（向后兼容）：**

```c
esp_err_t pca9685_init(void)  // 仍然自创 I2C 总线
```

### 2. **Servo.h** - 暴露新的初始化 API

```c
// 原始初始化（自动创建 I2C 总线）
esp_err_t pca9685_init(void);

// 新增：使用外部 I2C 总线初始化（支持一主多从）
esp_err_t pca9685_init_with_bus(i2c_master_bus_handle_t bus_handle);
```

### 3. **esp32_hw_i2c.h/.c** - U8G2 OLED 驱动升级

**新增函数：**

```c
esp_err_t u8g2_esp32_i2c_init_with_bus(
    u8g2_esp32_i2c_ctx_t *ctx, 
    i2c_master_bus_handle_t bus_handle
)
```

**功能：** 不创建新的 I2C 总线，而是使用外部提供的总线句柄

### 4. **main.c** - 集中管理所有 I2C 设备

**四个初始化层次：**

#### `init_i2c_bus()` - 初始化唯一的 I2C 总线

```c
static esp_err_t init_i2c_bus(void)
{
    i2c_master_bus_config_t bus_config = {
        .i2c_port = I2C_NUM_0,
        .sda_io_num = GPIO_NUM_38,
        .scl_io_num = GPIO_NUM_14,
        .clk_source = I2C_CLK_SRC_DEFAULT,
        .glitch_ignore_cnt = 7,
        .flags.enable_internal_pullup = 1,
    };

    return i2c_new_master_bus(&bus_config, &g_i2c_bus_handle);
}
```

#### `init_servo_hardware()` - 初始化舵机硬件

```c
static esp_err_t init_servo_hardware(void)
{
    esp_err_t err = servo_hw_init(g_i2c_bus_handle);
    return err;
}
```

#### `init_oled_display()` - 初始化 OLED 显示屏

```c
static esp_err_t init_oled_display(void)
{
    u8g2_esp32_i2c_ctx_t i2c_ctx = {
        .cfg = U8G2_ESP32_I2C_CONFIG_DEFAULT(),
    };

    esp_err_t err = u8g2_esp32_i2c_init_with_bus(&i2c_ctx, g_i2c_bus_handle);

    u8g2_Setup_ssd1306_i2c_128x64_noname_f(&u8g2, U8G2_R0,
        u8x8_byte_esp32_hw_i2c, u8x8_gpio_and_delay_esp32_i2c);

    u8g2_InitDisplay(&u8g2);
    u8g2_SetPowerSave(&u8g2, 0);
    return err;
}
```

---

## 新的组件边界

### `servo_hw_init()` 和 `servo_app_init()` 的职责

- `servo_hw_init(i2c_master_bus_handle_t bus_handle)`
  - 负责 PCA9685 硬件初始化与频率设置
  - 属于“硬件初始化层”
- `servo_app_init()`
  - 负责舵机命令队列、任务启动与业务逻辑
  - 不再负责硬件初始化

---

## 使用示例

### 基本初始化流程

```c
void app_main(void)
{
    // 1. 初始化唯一的 I2C 总线
    if (init_i2c_bus() != ESP_OK) {
        ESP_LOGE(TAG, "I2C 初始化失败");
        return;
    }

    // 2. 在同一总线上添加 OLED 设备
    if (init_oled_display() != ESP_OK) {
        ESP_LOGW(TAG, "OLED 初始化失败，但继续运行");
    }

    // 3. 在同一总线上添加舵机控制器
    if (init_servo_hardware() != ESP_OK) {
        ESP_LOGW(TAG, "舵机硬件初始化失败，但继续运行");
    }

    // 正常使用
    pca9685_set_angle(0, 90.0f);  // 舵机动作
    u8g2_DrawStr(&u8g2, 0, 10, "Hello");  // 显示文字
}
```

---

## 关键优势

| 方面 | 之前 | 改进后 |
| --- | --- | --- |
| **I2C 总线数量** | 2 条（浪费资源）  | 1 条（共享） |
| **代码重复** | 每个设备都初始化总线 | 只初始化一次 |
| **灵活性** | 低（硬编码总线配置） | 高（参数化） |
| **扩展性** | 差（难以添加新设备） | 好（在同一总线上添加） |
| **资源占用** | 更多 | 更少 |

---

## 添加新 I2C 设备的步骤

假设要添加第三个 I2C 设备（如温度传感器，地址 `0x48`）：

1. **编写驱动程序**（支持外部 bus_handle）：
   
   ```c
   esp_err_t temp_sensor_init_with_bus(i2c_master_bus_handle_t bus_handle)
   {
       // 将 bus_handle 传给驱动初始化函数
   }
   ```

2. **在 main.c 中添加初始化函数**：
   
   ```c
   static esp_err_t init_temp_sensor(void)
   {
       return temp_sensor_init_with_bus(g_i2c_bus_handle);
   }
   ```

3. **在 app_main 中调用**：
   
   ```c
   init_temp_sensor();
   ```

无需修改 I2C 总线配置，直接添加即可！

---

## 故障排除

### 问题：OLED 无法显示

**检查项：**

- OLED 地址是否为 `0x3C`（配置中 `.dev_addr_7bit = 0x3C`）
- SDA/SCL 引脚是否正确（GPIO38/GPIO14）
- I2C 总线是否正确初始化

### 问题：舵机不动作

**检查项：**

- PCA9685 地址是否为 `0x40`（头文件中 `#define PCA_Addr 0x40`）
- PCA9685_init_with_bus 是否成功返回
- `pca9685_set_freq(50)` 是否被调用

### 问题：两个设备同时出错

**检查项：**

- I2C 总线是否初始化成功（检查返回值）
- I2C 引脚是否被正确配置
- ESP32 是否启用了内部上拉电阻

---

## 参考资源

- **ESP32 I2C Master API**：https://docs.espressif.com/projects/esp-idf/en/latest/esp32/api-reference/peripherals/i2c.html
- **u8g2 库**：https://github.com/olikraus/u8g2
- **PCA9685 数据手册**：https://www.nxp.com/docs/en/data-sheet/PCA9685.pdf

---

## 总结

✅ **一条 I2C 总线** - 共享 SDA/SCL 引脚  
✅ **多个从设备** - 使用不同地址（0x40, 0x3C, ...）  
✅ **集中管理** - 在 main.c 中管理所有初始化  
✅ **易于扩展** - 添加新设备只需实现 `xxx_init_with_bus(bus_handle)`  
✅ **向后兼容** - 原有 `pca9685_init()` 仍可单独使用，新的 `servo_hw_init()` 供共享 I2C 总线时使用

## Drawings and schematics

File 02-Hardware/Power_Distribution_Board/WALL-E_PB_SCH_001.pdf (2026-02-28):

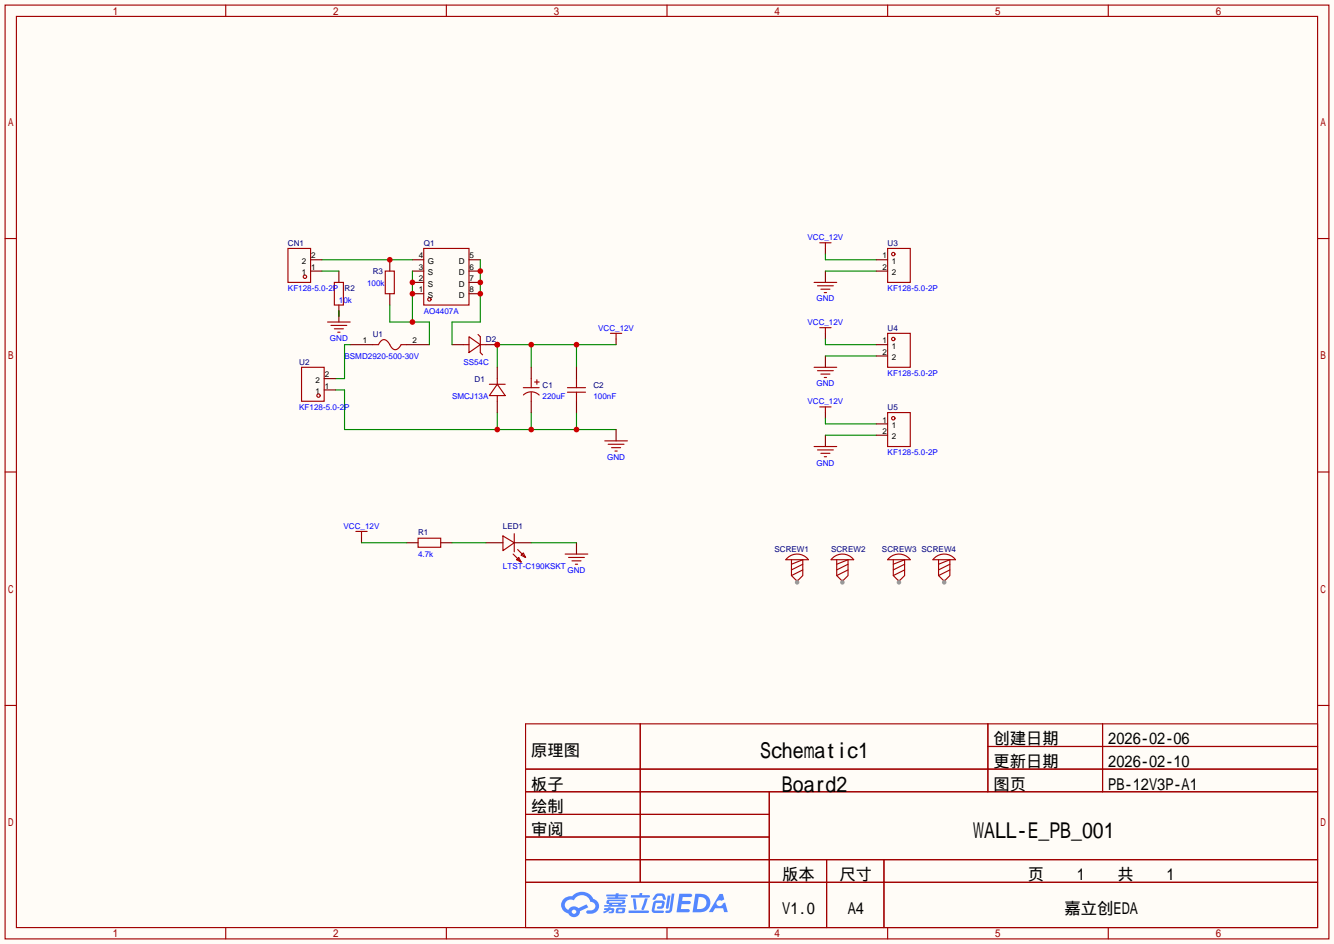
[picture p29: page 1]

原理图 | Schematic1 | 创建日期 | 2026-02-06

更新日期 | 2026-02-10

板子 | Board2 | 图页 | PB-12V3P-A1
绘制 | | WALL-E_PB_001
审阅

V1.0 | A4 | 嘉立创EDA

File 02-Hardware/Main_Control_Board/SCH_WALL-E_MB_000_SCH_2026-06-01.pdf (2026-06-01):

# DC-DC

# 电源电路

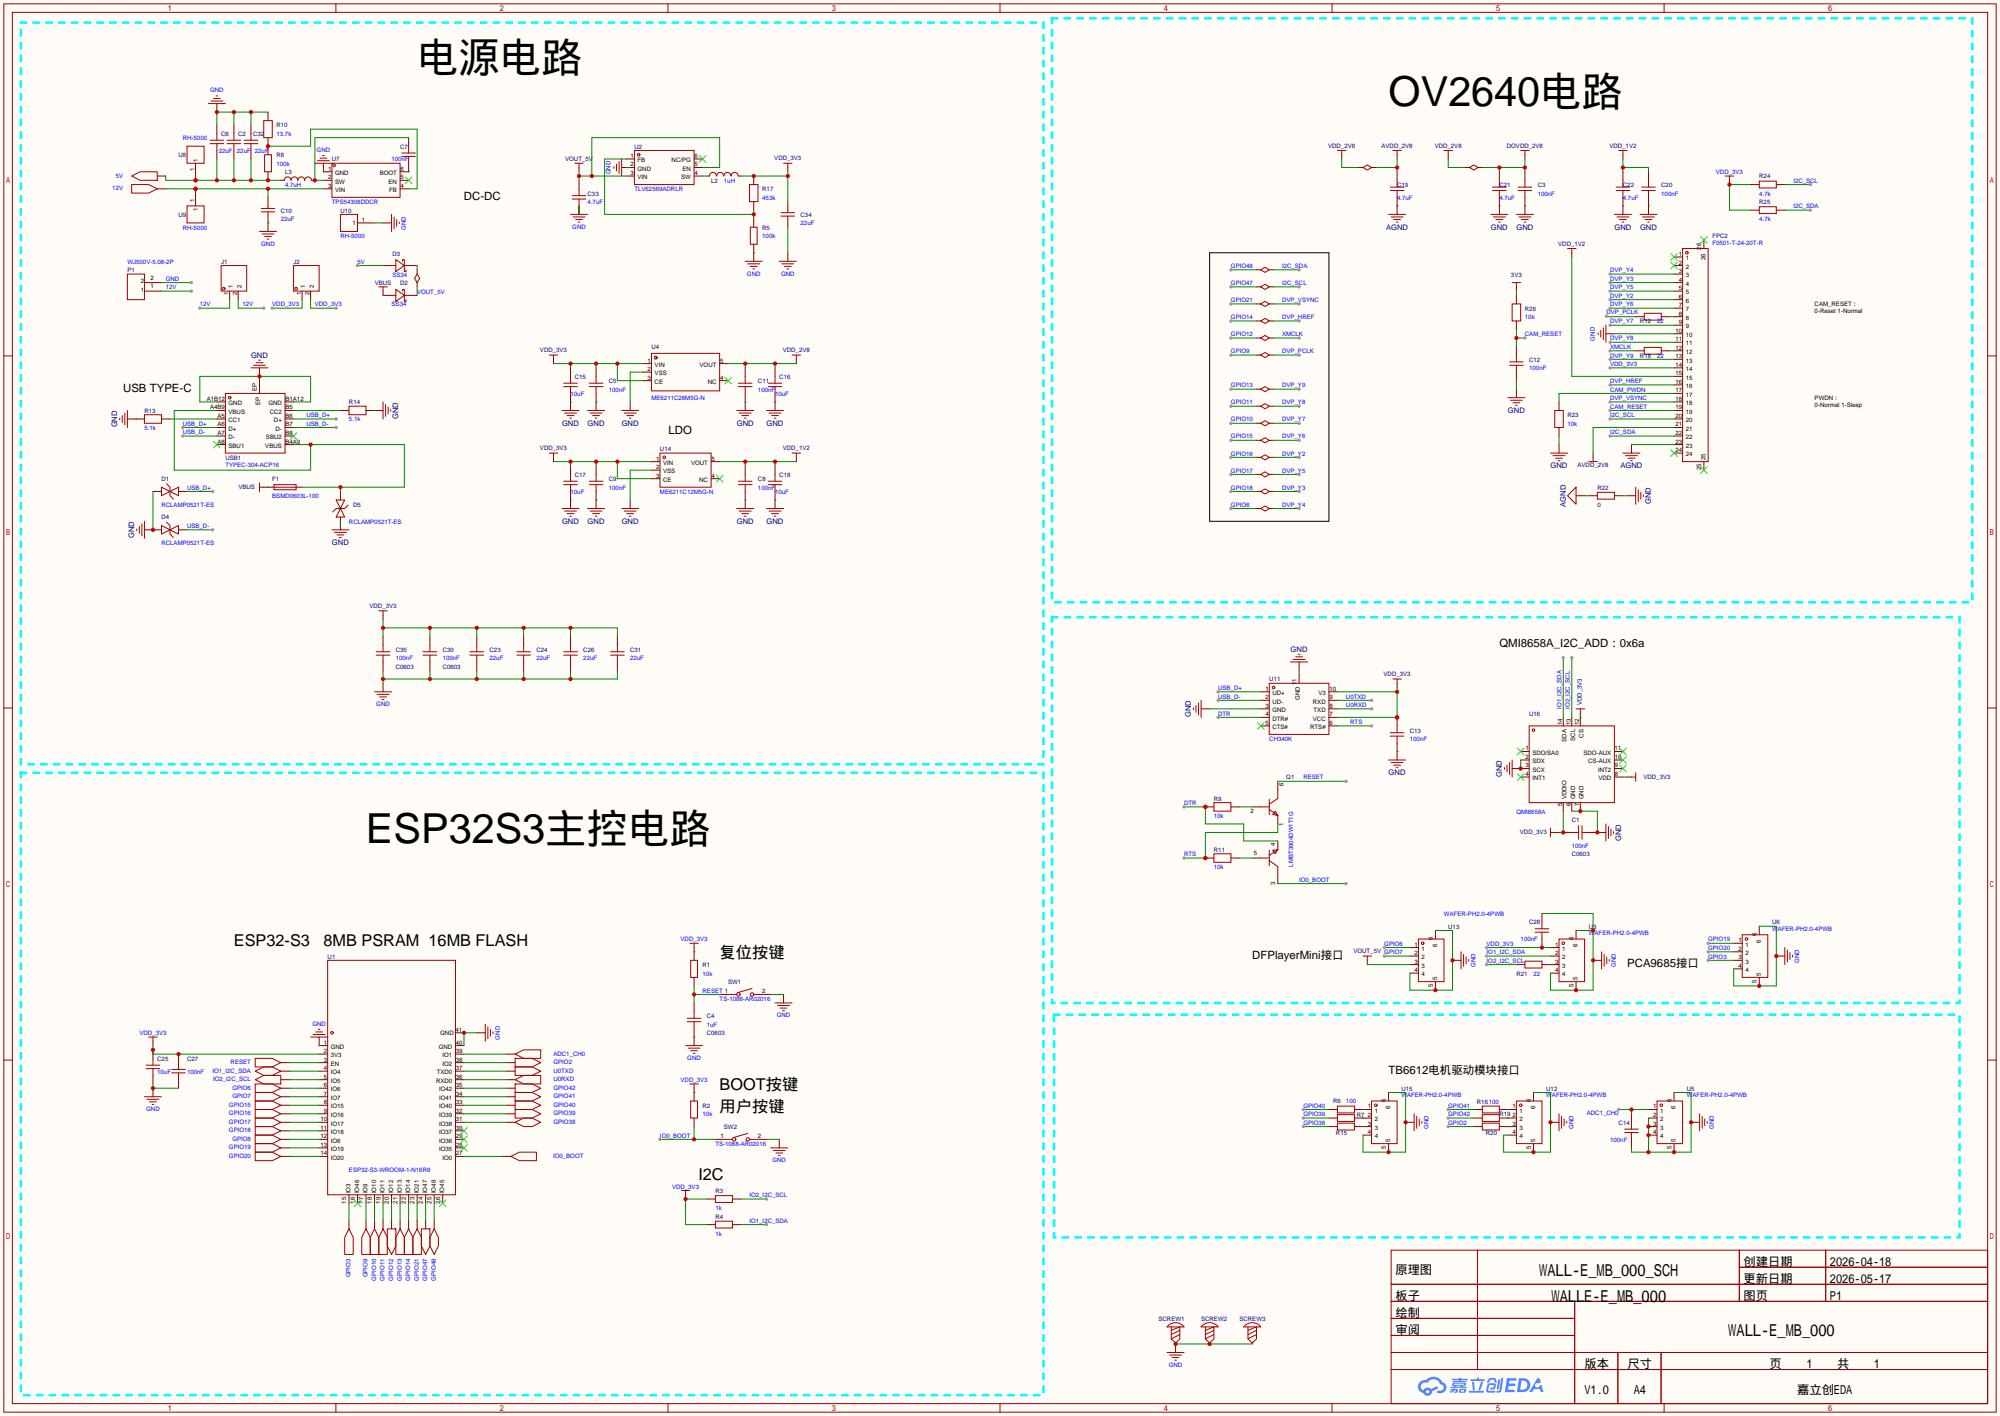
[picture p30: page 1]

原理图 | WALL-E_MB_000_SCH | 创建日期 | 2026-04-18

更新日期 | 2026-05-17

板子 | WALLE-E_MB_000 | 图页 | P1
绘制 | | WALL-E_MB_000
审阅

V1.0 | A4 | 嘉立创EDA

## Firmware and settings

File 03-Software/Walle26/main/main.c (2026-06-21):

/*
 * 项目名称：基于 ESP32 的移动机器人无线图传系统
 * Copyright (C) 2026 gclv
 * * This program is free software: you can redistribute it and/or modify
 * it under the terms of the GNU General Public License as published by
 * the Free Software Foundation, either version 3 of the License, or
 * (at your option) any later version. 
 */
#include <stdio.h>
#include <string.h>
#include <u8g2.h>
#include "esp_system.h"
#include "esp_log.h"
#include "esp_console.h"
#include "esp_vfs_dev.h"
#include "esp_vfs_fat.h"
#include "nvs.h"
#include "nvs_flash.h"
#include "command.h"
#include "camera_app.h"
#include "DC_Motor.h"
#include "Servo_app.h"
#include "wifi.h"
#include "DFPlayerMini.h"
#include "esp32_hw_i2c.h"
#include "display.h"
#include "battery.h"
#include "animation_engine.h"
#include "energy_manager.h"



/*
 * We warn if a secondary serial console is enabled. A secondary serial console is always output-only and
 * hence not very useful for interactive console applications. If you encounter this warning, consider disabling
 * the secondary serial console in menuconfig unless you know what you are doing.
 */
#if SOC_USB_SERIAL_JTAG_SUPPORTED
#if !CONFIG_ESP_CONSOLE_SECONDARY_NONE
#warning "A secondary serial console is not useful when using the console component. Please disable it in menuconfig."
#endif
#endif

static const char* TAG = "WALL-E";
#define PROMPT_STR CONFIG_IDF_TARGET


/* Console command history can be stored to and loaded from a file.
 * The easiest way to do this is to use FATFS filesystem on top of
 * wear_levelling library.
 */
#if CONFIG_CONSOLE_STORE_HISTORY

#define MOUNT_PATH "/data"
#define HISTORY_PATH MOUNT_PATH "/history.txt"

static void initialize_filesystem(void)
{
    static wl_handle_t wl_handle;
    const esp_vfs_fat_mount_config_t mount_config = {
            .max_files = 4,
            .format_if_mount_failed = true
    };
    esp_err_t err = esp_vfs_fat_spiflash_mount_rw_wl(MOUNT_PATH, "storage", &mount_config, &wl_handle);
    if (err != ESP_OK) {
        ESP_LOGE(TAG, "Failed to mount FATFS (%s)", esp_err_to_name(err));
        return;
    }
}
#endif // CONFIG_STORE_HISTORY

static void initialize_nvs(void)
{
    esp_err_t err = nvs_flash_init();
    if (err == ESP_ERR_NVS_NO_FREE_PAGES || err == ESP_ERR_NVS_NEW_VERSION_FOUND) {
        ESP_ERROR_CHECK( nvs_flash_erase() );
        err = nvs_flash_init();
    }
    ESP_ERROR_CHECK(err);
}

// ============ 全局 I2C 总线管理 ============
static i2c_master_bus_handle_t g_i2c_bus_handle = NULL;

// I2C 总线初始化（一主多从）
static esp_err_t init_i2c_bus(void)
{
    if (g_i2c_bus_handle != NULL) {
        ESP_LOGI(TAG, "I2C 总线已初始化");
        return ESP_OK;
    }

    i2c_master_bus_config_t bus_config = {
        .i2c_port = I2C_NUM_0,
        .sda_io_num = GPIO_NUM_4,
        .scl_io_num = GPIO_NUM_5,
        .clk_source = I2C_CLK_SRC_DEFAULT,
        .glitch_ignore_cnt = 7,
        .intr_priority = 0,
        .trans_queue_depth = 0,
        .flags.enable_internal_pullup = 1,
        .flags.allow_pd = 0,
    };

    esp_err_t err = i2c_new_master_bus(&bus_config, &g_i2c_bus_handle);
    if (err != ESP_OK) {
        ESP_LOGE(TAG, "I2C 总线创建失败: %s", esp_err_to_name(err));
        return err;
    }

    ESP_LOGI(TAG, "I2C 总线初始化成功 (I2C_NUM_0, SDA=GPIO4, SCL=GPIO5, 400kHz)");
    return ESP_OK;
}

// ============ U8G2 OLED 初始化 ============
u8g2_t u8g2;
static u8g2_esp32_i2c_ctx_t g_oled_i2c_ctx = {
    .cfg = U8G2_ESP32_I2C_CONFIG_DEFAULT(),
};

static esp_err_t init_oled_display(void)
{
    ESP_LOGI(TAG, "初始化 U8G2 OLED...");

    // 使用全局 I2C 总线初始化 U8G2
    esp_err_t err = u8g2_esp32_i2c_init_with_bus(&g_oled_i2c_ctx, g_i2c_bus_handle);
    if (err != ESP_OK) {
        ESP_LOGE(TAG, "U8G2 I2C 上下文初始化失败: %s", esp_err_to_name(err));
        return err;
    }

    // 设置 U8G2 外观
    u8g2_Setup_ssd1306_i2c_128x64_noname_f(&u8g2, U8G2_R1,
        u8x8_byte_esp32_hw_i2c, u8x8_gpio_and_delay_esp32_i2c);

    // 初始化显示屏
    u8g2_InitDisplay(&u8g2);
    u8g2_SetPowerSave(&u8g2, 0); // 关闭省电模式

    u8g2_ClearBuffer(&u8g2);
    u8g2_SendBuffer(&u8g2);

    ESP_LOGI(TAG, "U8G2 OLED 初始化成功");
    return ESP_OK;
}

// ============ 舵机硬件初始化 ============
static esp_err_t init_servo_hardware(void)
{
    ESP_LOGI(TAG, "初始化舵机硬件...");

    esp_err_t err = Servo_hw_Init(g_i2c_bus_handle);
    if (err != ESP_OK) {
        ESP_LOGE(TAG, "舵机硬件初始化失败: %s", esp_err_to_name(err));
        return err;
    }

    ESP_LOGI(TAG, "舵机硬件初始化成功");
    return ESP_OK;
}

// ============ I2C 设备初始化层 ============
static void init_i2c_devices(void)
{
    if (init_i2c_bus() != ESP_OK) {
        ESP_LOGE(TAG, "I2C 总线初始化失败，程序退出");
        return;
    }

    if (init_oled_display() != ESP_OK) {
        ESP_LOGE(TAG, "OLED 初始化失败");
        // 继续运行，不影响其他功能
    }

    if (init_servo_hardware() != ESP_OK) {
        ESP_LOGE(TAG, "舵机硬件初始化失败");
        // 继续运行，不影响其他功能
    }

    ESP_LOGI(TAG, "所有 I2C 设备初始化完成");
}

void app_main(void)
{
    esp_console_repl_t *repl = NULL;
    esp_console_repl_config_t repl_config = ESP_CONSOLE_REPL_CONFIG_DEFAULT();
    /* Prompt to be printed before each line.
     * This can be customized, made dynamic, etc.
     */
    repl_config.prompt = PROMPT_STR ">";
    repl_config.max_cmdline_length = CONFIG_CONSOLE_MAX_COMMAND_LINE_LENGTH;

    initialize_nvs();
    // 初始化 I2C 设备和总线
    init_i2c_devices();

    // 初始化电池电压监测
    battery_init();
    
    DFPlayerMini_Init();
    DFPlayerMini_SetVolume(26);     /* 统一音量 */
    wifi_init();
    init_camera();

    DC_Motor_Init();
    motor_cmd_queue = xQueueCreate(1, sizeof(motor_cmd_t));
    if (motor_cmd_queue == NULL) {
        ESP_LOGE("MAIN", "队列创建失败！");
        return;
    }

    // 创建独立运行的电机控制任务
    xTaskCreatePinnedToCore(motor_control_task, "motor_ctrl_task", 4096, NULL, 15, NULL, 1);
    // 初始化舵机控制系统
    Servo_app_Init();
    // 初始化动画引擎
    anim_engine_init();
    anim_engine_enable_idle(false);   // 能量管理器接管空闲行为控制
    energy_manager_init();           // 启动能量管理系统

#if CONFIG_CONSOLE_STORE_HISTORY
    initialize_filesystem();
    repl_config.history_save_path = HISTORY_PATH;
    ESP_LOGI(TAG, "Command history enabled");
#else
    ESP_LOGI(TAG, "Command history disabled");
#endif

    /* Register commands */
    esp_console_register_help_command();
    register_system_common();

    register_nvs();

    register_motor_set();
    register_motor_stop();
    register_servo();
    register_servo_key();
    register_servo_calib();
    register_dfplayer_play_folder();
    register_anim_debug();
    register_anim_idle();
    register_motor_ripple_test();

#if defined(CONFIG_ESP_CONSOLE_UART_DEFAULT) || defined(CONFIG_ESP_CONSOLE_UART_CUSTOM)
    esp_console_dev_uart_config_t hw_config = ESP_CONSOLE_DEV_UART_CONFIG_DEFAULT();
    ESP_ERROR_CHECK(esp_console_new_repl_uart(&hw_config, &repl_config, &repl));

#elif defined(CONFIG_ESP_CONSOLE_USB_CDC)
    esp_console_dev_usb_cdc_config_t hw_config = ESP_CONSOLE_DEV_CDC_CONFIG_DEFAULT();
    ESP_ERROR_CHECK(esp_console_new_repl_usb_cdc(&hw_config, &repl_config, &repl));

#elif defined(CONFIG_ESP_CONSOLE_USB_SERIAL_JTAG)
    esp_console_dev_usb_serial_jtag_config_t hw_config = ESP_CONSOLE_DEV_USB_SERIAL_JTAG_CONFIG_DEFAULT();
    ESP_ERROR_CHECK(esp_console_new_repl_usb_serial_jtag(&hw_config, &repl_config, &repl));

#else
#error Unsupported console type
#endif

    ESP_ERROR_CHECK(esp_console_start_repl(repl));

    // 主循环：每 2 秒刷新 OLED 显示电池电量
    while(1) {
        uint32_t mv = battery_get_voltage_mv();
        uint8_t pct = battery_get_percentage();
        display_battery_show(pct, mv);
        vTaskDelay(pdMS_TO_TICKS(2000));
    }
}

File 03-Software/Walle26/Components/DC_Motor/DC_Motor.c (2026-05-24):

#include "DC_Motor.h"

static motor_control_t motors[2] = {
    {.id = MOTOR_LEFT,
     .channel = LEDC_CHANNEL,
     .gpio1 = DC_MOTOR_LEFT_GPIO_1,
     .gpio2 = DC_MOTOR_LEFT_GPIO_2,
     .state = MOTOR_STATE_IDLE,
     .current_speed = 0,
     .target_speed = 0,
     .stage1_duration_ms = 0,
     .stage2_duration_ms = 0,
     .sem = NULL},

    {.id = MOTOR_RIGHT,
     .channel = LEDC_CHANNEL + 1,
     .gpio1 = DC_MOTOR_RIGHT_GPIO_1,
     .gpio2 = DC_MOTOR_RIGHT_GPIO_2,
     .state = MOTOR_STATE_IDLE,
     .current_speed = 0,
     .target_speed = 0,
     .stage1_duration_ms = 0,
     .stage2_duration_ms = 0,
     .sem = NULL}};

/* 13-bit 分辨率下最大占空比 */
static const uint32_t MAX_DUTY = ((1u << LEDC_DUTY_RES) - 1);

/* 速度值 (-100~100) → PWM 占空比（绝对值取 duty，方向由 GPIO 控制） */
static inline uint32_t calculate_duty(int8_t speed)
{
    return (uint32_t)((abs(speed) * MAX_DUTY) / MOTOR_SPEED_MAX);
}

/* 从硬件 GPIO 电平 + duty 反算当前速度（含四舍五入） */
static int8_t duty_to_speed(uint32_t duty, int dir_pin1, int dir_pin2)
{
    int8_t speed = (int8_t)((duty * MOTOR_SPEED_MAX + (MAX_DUTY / 2)) / MAX_DUTY);
    if (dir_pin1 == 1 && dir_pin2 == 0)
        return speed;
    else if (dir_pin1 == 0 && dir_pin2 == 1)
        return -speed;
    return 0;
}

static int8_t motor_get_current_speed(motor_control_t *motor)
{
    int dir1 = gpio_get_level(motor->gpio1);
    int dir2 = gpio_get_level(motor->gpio2);
    uint32_t duty = ledc_get_duty(LEDC_MODE, motor->channel);
    return duty_to_speed(duty, dir1, dir2);
}

static void motor_set_direction(motor_control_t *motor, int8_t speed)
{
    if (speed > 0)
    {
        gpio_set_level(motor->gpio1, 1);
        gpio_set_level(motor->gpio2, 0);
    }
    else if (speed < 0)
    {
        gpio_set_level(motor->gpio1, 0);
        gpio_set_level(motor->gpio2, 1);
    }
    else
    {
        gpio_set_level(motor->gpio1, 0);
        gpio_set_level(motor->gpio2, 0);
    }
}

static IRAM_ATTR bool motor_fade_cb(const ledc_cb_param_t *param, void *user_arg)
{
    motor_control_t *motor = (motor_control_t *)user_arg;

    if (param->event != LEDC_FADE_END_EVT)
        return false;

    BaseType_t need_yield = pdFALSE;

    if (motor->state == MOTOR_STATE_TO_0)
    {
        /* 第一阶段完成（已减速到 0）→ 换向 → 第二阶段加速到目标 */
        motor_set_direction(motor, motor->target_speed);
        uint32_t target_duty = calculate_duty(motor->target_speed);
        ledc_set_fade_with_time(LEDC_MODE, motor->channel, target_duty, motor->stage2_duration_ms);
        ledc_fade_start(LEDC_MODE, motor->channel, LEDC_FADE_NO_WAIT);
        motor->state = MOTOR_STATE_TO_TARGET;
    }
    else if (motor->state == MOTOR_STATE_TO_TARGET)
    {
        motor->state = MOTOR_STATE_IDLE;
        motor->current_speed = motor->target_speed;
        if (motor->sem)
            xSemaphoreGiveFromISR(motor->sem, &need_yield);
    }

    return (need_yield == pdTRUE);
}

esp_err_t DC_Motor_SetSpeedSmoothAsync(motor_id_t motor_id, int8_t target_speed, uint32_t duration_ms)
{
    // 参数验证
    if (motor_id != MOTOR_LEFT && motor_id != MOTOR_RIGHT)
    {
        return ESP_ERR_INVALID_ARG;
    }
    if (target_speed > MOTOR_SPEED_MAX || target_speed < MOTOR_SPEED_MIN)
    {
        return ESP_ERR_INVALID_ARG;
    }

    motor_control_t *motor = &motors[motor_id]; // 为什么不直接用motors[motor_id]直接访问？因为我们需要一个指针来传递给回调函数，而 motors[motor_id] 是一个结构体实例，不能直接作为指针使用。通过定义 motor_control_t *motor，我们创建了一个指向该结构体实例的指针，这样我们就可以在回调函数中访问和修改该实例的成员变量。(thanks to chatGPT for the explanation)

    // if motor is currently fading, stop current fade.
    if (motor->state != MOTOR_STATE_IDLE)
    {
        ledc_fade_stop(LEDC_MODE, motor->channel);
        motor->state = MOTOR_STATE_IDLE;
    }

    // get current speed as starting point for fade
    int8_t current_speed = motor_get_current_speed(motor);
    if (current_speed == target_speed)
        return ESP_OK; // already at target

    // if duration is zero, just set speed immediately
    if (duration_ms == 0)
    {
        motor_set_direction(motor, target_speed);
        uint32_t duty = calculate_duty(target_speed);
        ledc_set_duty(LEDC_MODE, motor->channel, duty);
        ledc_update_duty(LEDC_MODE, motor->channel);
        motor->current_speed = target_speed;
        return ESP_OK;
    }

    // 判断方向是否改变，如果改变了需要先淡出到0再淡入到目标速度
    bool direction_change = (current_speed > 0 && target_speed < 0) || (current_speed < 0 && target_speed > 0);

    if (!direction_change)
    {
        // 同方向：直接从当前 duty 渐变到目标 duty
        motor_set_direction(motor, target_speed);
        motor->target_speed = target_speed;
        motor->state = MOTOR_STATE_TO_TARGET;
        motor->stage2_duration_ms = duration_ms; // 为什么要这样可是回调函数中没有用到我是说在不用反向的情况下就用不到motor->stage2_duration_ms吧？是的，在不需要反向的情况下，motor->stage2_duration_ms 这个字段确实没有被使用到。这个字段主要是为了在需要先淡出到0再淡入到目标速度的情况下，存储第二阶段的持续时间，以便在回调函数中使用。对于同方向的情况，我们直接使用传入的 duration_ms 来设置淡入时间，而不需要区分阶段，因此 motor->stage2_duration_ms 在这种情况下没有实际作用。不过，为了保持代码的一致性和简洁性，我们仍然将 duration_ms 赋值给 motor->stage2_duration_ms，这样在回调函数中就可以统一使用 motor->stage2_duration_ms 来获取淡入时间，无论是否需要反向。thanks to chatGPT for the explanation
        uint32_t target_duty = calculate_duty(target_speed);
        ledc_set_fade_with_time(LEDC_MODE, motor->channel, target_duty, duration_ms);
        ledc_fade_start(LEDC_MODE, motor->channel, LEDC_FADE_NO_WAIT);
    }
    else
    {
        // 反方向：先减速到 0（阶段一）→ 换向 → 再加速到目标（阶段二）
        // 两阶段时长按 |当前速|:|目标速| 比例分配
        uint32_t cur_abs = abs(current_speed);
        uint32_t tar_abs = abs(target_speed);
        uint32_t total_diff = cur_abs + tar_abs;
        if (total_diff == 0)
            return ESP_OK;

        motor->stage1_duration_ms = (duration_ms * cur_abs) / total_diff;
        motor->stage2_duration_ms = duration_ms - motor->stage1_duration_ms;

        // 阶段一：方向引脚不动，仅 fade 到 0
        motor->target_speed = target_speed;
        motor->state = MOTOR_STATE_TO_0;
        ledc_set_fade_with_time(LEDC_MODE, motor->channel, 0, motor->stage1_duration_ms);
        ledc_fade_start(LEDC_MODE, motor->channel, LEDC_FADE_NO_WAIT);
    }

    return ESP_OK;
}


/*
 * @brief Stop both motors by fading PWM duty to zero.
 * @param duration_ms Fade duration in ms. 0 = immediate stop.
 * Uses the LEDC fade API to smoothly reduce both motors to zero speed.
 */
esp_err_t DC_Motor_Stop(uint32_t duration_ms)
{
    DC_Motor_SetSpeedSmoothAsync(MOTOR_LEFT, 0, duration_ms);
    DC_Motor_SetSpeedSmoothAsync(MOTOR_RIGHT, 0, duration_ms);

    ESP_LOGI(__func__, "the speed before stopping: left motor %d, right motor %d", motors[MOTOR_LEFT].current_speed, motors[MOTOR_RIGHT].current_speed);

    return ESP_OK;
}

/* 全局队列句柄：main.c 创建，wifi.c 写入，本任务读取 */
QueueHandle_t motor_cmd_queue = NULL;

/* 心跳超时阈值：超过此时间未收到指令则判定链路断开 */
#define HEARTBEAT_TIMEOUT_MS 800
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

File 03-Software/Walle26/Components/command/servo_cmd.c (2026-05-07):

#include "PCA9685.h"
#include <stdio.h>
#include <stdint.h>
#include <inttypes.h>
#include "esp_console.h"
#include "argtable3/argtable3.h"
#include "freertos/FreeRTOS.h"
#include "freertos/task.h"  
#include "Servo_app.h"


static const char *TAG = "CMD_SERVO";

static struct {
    struct arg_int *channel;
    struct arg_dbl *angle;
    struct arg_int *duration_ms;
    struct arg_end *end;
} servo_args;

static int cmd_servo_move(int argc, char **argv){
    int nerrors = arg_parse(argc, argv, (void **)&servo_args);
    if(nerrors != 0){
        arg_print_errors(stderr, servo_args.end, argv[0]);
        return -1;
    }

    int channel = servo_args.channel->ival[0];
    if(channel < 0 || channel > 15){
        ESP_LOGE(TAG, "Invalid channel: %d. Channel must be between 0 and 15.", channel);
        return -1;
    }
    float angle = (float)servo_args.angle->dval[0];
    if(angle < 0.0f || angle > 180.0f){
        ESP_LOGE(TAG, "Invalid angle: %.2f. Angle must be between 0 and 180.", angle);
        return -1;
    }
    uint32_t duration_ms = (uint32_t)servo_args.duration_ms->ival[0];

    walle_servo_set_angle(channel, angle, duration_ms);
    ESP_LOGI(TAG, "Moving servo %d to %.2f degrees over %" PRIu32 " ms", channel, angle, duration_ms);
    return 0;
}


void register_servo(){
    servo_args.channel = arg_int1(NULL, NULL, "channel", "Servo channel (0-15)");
    servo_args.angle = arg_dbl1(NULL, NULL, "angle", "Servo angle (0-180)");
    servo_args.duration_ms = arg_int1(NULL, NULL, "duration", "Movement duration (ms)");
    servo_args.end = arg_end(4);

    const esp_console_cmd_t cmd_servo = {
        .command = "servo",
        .help = "Move servo to specified angle over specified duration",
        .hint = NULL,
        .func = &cmd_servo_move,
        .argtable = &servo_args
    };
    esp_console_cmd_register(&cmd_servo);

}

// Argument structure for servo_key command
static struct {
    struct arg_int *channel;
    struct arg_end *end;
} servo_key_args;

// Command function for interactive servo control with keyboard input
static int cmd_servo_key(int argc, char **argv){
    // Parse command line arguments
    int nerrors = arg_parse(argc, argv, (void **)&servo_key_args);
    if(nerrors != 0){
        arg_print_errors(stderr, servo_key_args.end, argv[0]);
        return -1;
    }

    // Validate channel number
    int channel = servo_key_args.channel->ival[0];
    if(channel < 0 || channel > 15){
        ESP_LOGE(TAG, "Invalid channel: %d. Channel must be between 0 and 15.", channel);
        return -1;
    }

    // Initialize servo to its default angle as starting position
    float current_angle = get_servo_angle(channel);
    pca9685_set_angle(channel, current_angle);
    ESP_LOGI(TAG, "Servo %d started at default %.1f degrees. W:+1 S:-1 A:+10 D:-10 Q:quit", channel, current_angle);

    // Main control loop for keyboard input
    char input_buffer[10];  // Buffer for user input
    while(1) {
        // Display current angle and prompt for input
        printf("Current angle: %.1f degrees. Press W/S/Q/A/D: ", current_angle);
        fflush(stdout);  // Ensure prompt is displayed immediately

        // Read a line of input from user
        if (fgets(input_buffer, sizeof(input_buffer), stdin) == NULL) {
            break;  // Exit if input fails
        }

        // Get the first character from input
        int ch = input_buffer[0];
        if (ch == '\0' || ch == '\n') continue;  // Skip empty input

        // Handle 'W' key: increase angle by 1 degree
        if(ch == 'W' || ch == 'w') {
            if(current_angle < 180.0f) {
                current_angle += 1.0f;
                pca9685_set_angle(channel, current_angle);
                ESP_LOGI(TAG, "Angle increased to %.1f degrees", current_angle);
            } else {
                ESP_LOGW(TAG, "Angle already at maximum (180 degrees)");
            }
        }
        // Handle 'S' key: decrease angle by 1 degree
        else if(ch == 'S' || ch == 's') {
            if(current_angle > 0.0f) {
                current_angle -= 1.0f;
                pca9685_set_angle(channel, current_angle);
                ESP_LOGI(TAG, "Angle decreased to %.1f degrees", current_angle);
            } else {
                ESP_LOGW(TAG, "Angle already at minimum (0 degrees)");
            }
        }
        else if(ch == 'A' || ch == 'a') {
            if(current_angle < 180.0f) {
                current_angle += 10.0f;
                if(current_angle > 180.0f) current_angle = 180.0f; // Clamp to max
                pca9685_set_angle(channel, current_angle);
                ESP_LOGI(TAG, "Angle increased to %.1f degrees", current_angle);
            } else {
                ESP_LOGW(TAG, "Angle already at maximum (180 degrees)");
            }
        }
        else if(ch == 'D' || ch == 'd') {
            if(current_angle > 0.0f) {
                current_angle -= 10.0f;
                if(current_angle < 0.0f) current_angle = 0.0f; // Clamp to min
                pca9685_set_angle(channel, current_angle);
                ESP_LOGI(TAG, "Angle decreased to %.1f degrees", current_angle);
            } else {
                ESP_LOGW(TAG, "Angle already at minimum (0 degrees)");
            }
        }
        // Handle 'Q' key: quit the control loop
        else if(ch == 'Q' || ch == 'q') {
            current_angle = get_servo_angle(channel);
            pca9685_set_angle(channel, current_angle); // Reset to default angle before exiting
            ESP_LOGI(TAG, "Exiting servo key control, reset to default %.1f degrees.", current_angle);
            break;
        }
        // Handle invalid keys
        else {
            ESP_LOGW(TAG, "Invalid key: %c. Use W/S/Q/A/D.", ch);
        }
    }

    return 0;
}

void register_servo_key(){
    // Register the new servo_key command for keyboard control
    servo_key_args.channel = arg_int1(NULL, NULL, "channel", "Servo channel (0-15)");
    servo_key_args.end = arg_end(2);

    const esp_console_cmd_t cmd_servo_key_cmd = {
        .command = "servo_key",
        .help = "Interactive servo control with W/S keys (W: +1 deg, S: -1 deg, A: +10 deg, D: -10 deg, Q: quit)",
        .hint = NULL,
        .func = cmd_servo_key,
        .argtable = &servo_key_args
    };
    esp_console_cmd_register(&cmd_servo_key_cmd);
}

static struct {
    struct arg_int *channel;
    struct arg_dbl *min_angle;
    struct arg_dbl *max_angle;
    struct arg_int *reverse;
    struct arg_lit *save_cfg;
    struct arg_end *end;
} servo_calib;
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

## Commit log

2026-02-28 Initial commit: 第一次提交，DRS,3D设计源文件，WallE声音源文件
    [01-WallE-ESP32S3-WROOM-1-N16R8-GPIO信息_V1.0.xlsx, 01-WallE-PLN-v1.0.xlsx, New_Wall-e_Top.stl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]
2026-02-28 Refactor: 优化重构项目文件夹结构， 符合开源规范
2026-03-01 chore: 增加 Office 临时文件忽略规则
2026-03-01 chore: 更新 .gitignore
2026-03-03 chore: 添加Readme.md和LICENSE
    [Head_Center_MKIII.stl, Linkage_MKIII.stl]
2026-03-13 chore: 更新代码
    [OLED_frame_v2.stl, partitions_example.csv]
2026-03-19 chore: 更新电机驱动调试代码
2026-04-22 feat : 新增图传demo, 更新项目进度
    [01-WallE-ESP32S3-WROOM-1-N16R8-GPIO信息_V1.0.xlsx, arm-barrel-end-x2.3mf, partitions.csv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]
2026-05-05 refactor: 代码架构优化与项目清理
    - 重构 WiFi 模块: 分离控制服务器(:80)与图传服务器(:8081)，解决 MJPEG 阻塞 WebSocket 问题
    - 优化舵机控制: NVS 持久化移至 app 层，队列深度统一为1，任务优先级重排
    - 新增 KConfig Wi-Fi 配置菜单，凭证从硬编码迁移至 menuconfig
    - 移除多余类型转换修复未定义行为，修复 part_buf 声明
    - 更新 .gitignore 路径适配新目录结构，添加媒体文件忽略规则
    - 停止跟踪大型演示视频，清理重复/冗余文件
    - 重命名含空格和中文的文件名
    [arm-barrel-end-x2.3mf]
2026-05-07 refactor: 代码命名规范统一与 README 重构
    - Servo.h → PCA9685.h (文件名与芯片名匹配)
    - Servo 初始化函数统一为 Servo_hw_Init / Servo_app_Init 风格
    - DC_Motor 宏全大写 (DC_MOTOR_LEFT_GPIO_1)
    - DFPlayerMini 函数名统一 PascalCase 动词
    - 清理 include 依赖 (Servo_app.h 移除多余 command.h 引用)
    - 更新 hello 命令显示实际子系统状态
    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
2026-05-07 docs: README.md 更新 — 中期答辩展示优化
2026-05-07 docs: 替换电源分配板图片，精简 TI 参考文档
2026-05-07 docs: 添加 12V 三路电源分配板图片
2026-05-07 docs: 项目背景补充机械加工描述
2026-05-07 docs: 缩颈铜桥部分措辞严谨性修正
2026-05-07 docs: "缩颈铜桥"改为描述性表述"窄铜桥接地"
2026-05-07 docs: 阶段四参考文档替换为 split-gnd-plane 文章
2026-05-08 docs: 内部布线章节添加 internal_wiring 实物照片
2026-05-12 feat: 新增电池电压监测与OLED电量显示功能
    - 新增 battery 组件 (ADC oneshot, 2.5dB 衰减, 3S LiPo 查表)
    - 新增 display_battery_show() 实时电量显示 (百分比+电压)
    - 恢复 OLED 显示屏初始化与 I2C 总线集成
    - 新增 animation_engine 表情动画引擎
    - 新增 anim_debug 串口调试命令
    - 框架: PCA9685 舵机驱动优化, main 任务栈缩至 4KB
    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
2026-05-24 feat: WebSocket控制面板集成与能量管理系统接入
    - 新增嵌入式 index.html 控制面板与 /status 状态API
    - WebSocket 接入能量管理，收到指令自动打断动画
    - OLED 显示适配竖屏(U8G2_R1)，UI布局重新设计
    - 心跳刹车超时放宽至800ms，减少误触发
    - 摄像头LEDC通道改为CHANNEL_2，避免与电机冲突
    - 清理efuses.json与论文参考资料PDF(约500MB)
    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
    [TB6612双路驱动稳压模块（D153C).stp, TB6612四路驱动稳压模块（D24A).stp]
2026-06-01 项目完成
    [Left_Wheel_Frame_Bearings_and_spring.stl, Right_Wheel_Frame_Bearings_and_spring..stl, functional_part_x_2.stl]
2026-06-01 fix: README.md 文件名大小写修正与内容更新
    - 修正 git 跟踪文件名大小写 (Readme.md → README.md) 以匹配磁盘文件
    - 补充能量管理系统、动画引擎、Web 控制面板、电池监测等新功能说明
    - 添加性能测试数据与快速开始指南
    - 更新项目进度为已完成状态
2026-06-01 docs: 更正"动作状态机"状态标记（已实现）
    - 能量管理器已完整实现上电空闲行为选择 + WS 指令打断逻辑
    - 将"进行中"移至"已实现"并合并到能量管理系统条目
2026-06-01 fix: 修正 hello 命令中 OLED 显示状态 (Disabled → ON)
    OLED 初始化已在 main.c 中启用并正常运行（显示电池电量+太阳能图标），
    但 system.c 的 hello 诊断命令仍输出 OFF/Disabled，已修正。
    [system.c]
2026-06-01 docs: 移除快速开始章节，新增主控电路板原理图
    - 移除 README.md 中的"快速开始"章节
    - 新增主控电路板原理图 PDF
    - 在电路设计章节末尾添加原理图链接
    - 更新项目文件结构中的硬件目录
2026-06-21 docs: 重写 README 为开源项目规范格式，新增快速上手/引脚映射/硬件要点
    - 压缩"主控电路设计思路演进"6 阶段为精简的窄铜桥方案一节
    - 新增快速上手、引脚映射、通信协议等标准开源项目章节
    - 新增实物展示图库（3D 打印/PCB 布局/纹波波形/地平面噪声波形）
    - 修正 IP 显示方式（OLED→串口日志）、心跳超时值（500ms→800ms）、menuconfig 路径
    - 移除中期答辩风格的进展规划/功能演示章节
    - 调整 DFPlayer 默认音量 15→26
    [main.c]
2026-06-21 docs: 移除功能演示视频引用
2026-06-21 fix: 修复动画引擎空闲微表情永久阻塞导致音乐不播放的 Bug
    - 修正空闲禁用时 xQueueReceive 使用 portMAX_DELAY 导致任务永不苏醒
    (anim_engine_enable_idle(true) 后引擎无法感知)
    - 新增环境音效生成器 gen_ambient()，支持 12 种音效随机播放
    - 音效池加入独立音量控制，刺耳音效自动降低音量
    - 空闲间隔从 10~25s 缩短至 2~4s，增加表情频率
    - 权重表新增 AMBIENT(25%)，调整其他表情权重至总和 100

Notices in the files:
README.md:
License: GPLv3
